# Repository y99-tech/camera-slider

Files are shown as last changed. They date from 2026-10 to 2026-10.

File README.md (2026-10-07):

# DIY Motorized Camera Slider (ESP32 · Wi-Fi + Bluetooth)

A 3D-printed, belt-driven camera slider on **four 10 mm steel rods with 608ZZ roller bearings**, sized for a
**Sony A7 IV + FE 24-70 mm F2.8 GM II** (≈ 1.4 kg, ≈ 1.8 kg with a ball head).
It's built from parts you can buy in Egyptian electronics/maker shops, and every printed part fits a
**Creality Ender-3 V3**.

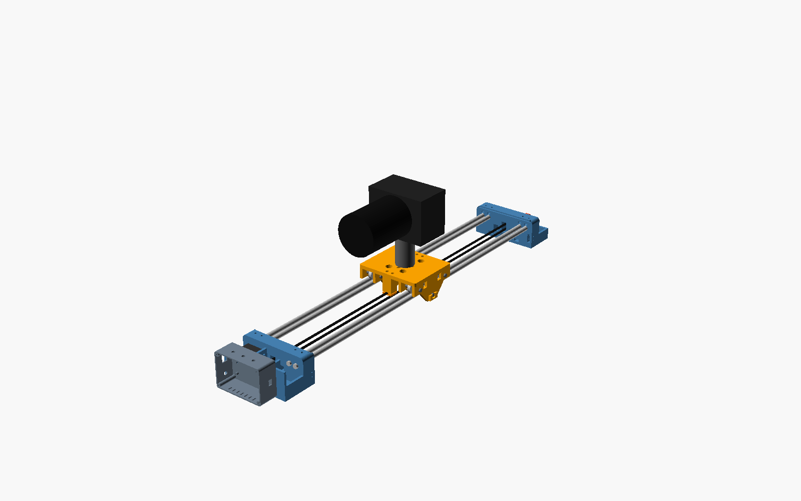
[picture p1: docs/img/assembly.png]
assembly


## Features

* **Mount it 3 ways:** on **2 tripods** (1/4"-20 and 3/8"-16 threads under each end), on **1 tripod**, or flat on a **table/floor** (optional wide feet).
* **Drive it 4 ways:**
  * **Motorized**: NEMA17 + silent TMC2209 driver, smooth eased moves for video
  * **By hand**: motor released, push the carriage
  * **Hand crank**: wheel on the idler end
  * **Fully free**: quick-release belt clamp
  * Also a rotary-knob "electronic hand wheel" on the control box
* **Control:**
  * **Wi-Fi web app** on any phone, no app to install. Uses its own hotspot or joins your Wi-Fi
  * **Bluetooth LE**: the same web page in Chrome, or any BLE-UART app
  * USB serial
  * Optional physical buttons
* **Moves:**
  * A→B with duration and ease, from 1 s to many hours
  * Bounce / loop
  * 6-keyframe sequencer
  * Shoot-move-shoot time-lapse with a camera shutter output
  * Stop-motion step
  * Homing with endstops, soft limits, and settings stored in flash

## Repository

| Folder | What's inside |
|---|---|
| [`cad/`](cad) | Parametric **OpenSCAD** source (`config.scad`, `parts.scad`, `assembly.scad`) and ready-to-print **STLs** in `cad/stl/` |
| [`firmware/`](firmware) | ESP32 firmware (PlatformIO / Arduino IDE) + the web UI (`firmware/ui/index.html`) |
| [`docs/SHOPPING_LIST.md`](docs/SHOPPING_LIST.md) | **Parts to buy**, with search keywords per shop group (+ [CSV](docs/SHOPPING_LIST.csv) to fill in prices) |
| [`docs/PRINTING.md`](docs/PRINTING.md) | Ender-3 V3 print settings, orientation, fit tuning |
| [`docs/WIRING.md`](docs/WIRING.md) | Pin map, power, motor current, endstops, shutter cable |
| [`docs/ASSEMBLY.md`](docs/ASSEMBLY.md) | Step-by-step build, mounting & hand-drive modes |
| [`docs/COMMANDS.md`](docs/COMMANDS.md) | Every command (Wi-Fi / Bluetooth / USB) and setting |

## Key specs

| | |
|---|---|
| Rails | 4 × 10 mm chrome rod, arranged as 2 twin-rod tracks 100 mm apart. 800 mm long (≈ 600 mm travel), up to 1000 mm |
| Bearings | 6 × 608ZZ rollers on M8 axles: 2 on top + 1 preloaded underneath per track. They roll in the groove between the two rods, with zero play and no sliding parts |
| Drive | NEMA17, GT2 6 mm belt, 20T pulleys → 80 steps/mm at 1/16 microstep |
| Speed | up to 120 mm/s (configurable), down to < 0.01 mm/s for long time-lapses |
| Controller | ESP32-WROOM-32 DevKit V1 + TMC2209 + LM2596 |
| Power | 12 V 2 A adapter or 3S 18650 pack |
| Camera mount | 3/8" centre hole + two 1/4" holes on the carriage, for a ball head or fluid head |

## Quick start

1. Buy the parts → [SHOPPING_LIST.md](docs/SHOPPING_LIST.md)
2. Print the STLs → [PRINTING.md](docs/PRINTING.md)
3. Wire it → [WIRING.md](docs/WIRING.md)
4. Assemble → [ASSEMBLY.md](docs/ASSEMBLY.md)
5. Flash the firmware → [firmware/README.md](firmware/README.md)
6. Join Wi-Fi **CamSlider-XXXX** (pw `slider123`), open **http://192.168.4.1**, press **Home**.

## Credits / inspiration

Feature ideas (A-B with ease, bounce, keyframe sequencer, time-lapse, stop motion) were inspired by the
excellent open-source [DigitalBird Camera Slider](https://github.com/digitalbird01/DigitalBird-Camera-Slider)
project ([Thingiverse](https://www.thingiverse.com/colinh3d/designs) ·
[YouTube](https://www.youtube.com/channel/UC7_bqm5Ea4Gn_P09HKYqyQA)). This repository is an independent
design. No DigitalBird files or code are copied here. If you want a pan/tilt head or a more complete
system, check out their designs and PCBs.

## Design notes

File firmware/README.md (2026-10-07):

# Firmware (ESP32)

ESP32 Arduino firmware built on [FastAccelStepper](https://github.com/gin66/FastAccelStepper) for smooth
step generation and [NimBLE-Arduino](https://github.com/h2zero/NimBLE-Arduino) for Bluetooth.

* `ui/index.html` is the control page. It's built into the firmware at compile time (`scripts/embed_ui.py`
  → `src/web_ui.h`). Edit the HTML, not the header.
* Everything goes through one text command parser (`src/commands.cpp`), whether it comes from Wi-Fi,
  Bluetooth, USB or the buttons.

## Flash with PlatformIO (recommended)

1. Install [VS Code](https://code.visualstudio.com) + the **PlatformIO** extension (or `pip install platformio`).
2. Open the `firmware` folder.
3. Plug in the ESP32 by USB (switch the slider's 12 V **off**). Then:
   ```
   pio run -t upload
   pio device monitor
   ```
   Some boards need the **BOOT** button held while "Connecting…" shows.
4. You should see:
   ```
   === DIY Camera Slider ===
   Wi-Fi AP "CamSlider-1A2B" password "slider123"  ->  http://192.168.4.1
   Bluetooth LE: advertising as "CamSlider"
   ```

USB driver: most DevKit V1 boards use **CP2102** or **CH340**. Install that driver on Windows if no COM port shows up.

## Flash with Arduino IDE

1. Boards Manager → install **esp32 by Espressif**, version **2.0.17**.
2. Library Manager → install **FastAccelStepper** (0.31.x) and **NimBLE-Arduino** (**1.4.x**, not 2.x).
3. Make a folder `CameraSlider`, copy all files from `src/` into it, add an empty `CameraSlider.ino`.
   Run `python scripts/embed_ui.py` first if you changed the HTML.
4. Board **ESP32 Dev Module**, Partition Scheme **Huge APP (3MB No OTA)**. Upload.

## Using it

### Wi-Fi (phone or laptop)
* Join **CamSlider-XXXX** (password `slider123`) → open **http://192.168.4.1**.
* Or set your home/studio Wi-Fi in *Settings* (name + password → Save → Reboot). Then open
  **http://slider.local** (or the IP printed on the serial monitor).

### Bluetooth
* **Android / desktop Chrome:** copy `ui/index.html` to the phone and open it in Chrome (or host it on
  GitHub Pages), tap **Bluetooth**, pick *CamSlider*. Same page, no Wi-Fi needed.
* **iPhone:** Safari has no Web Bluetooth. Use the free **Bluefruit Connect** or **nRF Connect** app →
  UART, and type the commands (e.g. `RUN 30 40 1`). Or use the Wi-Fi page.
* **Android terminal:** "Serial Bluetooth Terminal" app → Devices → Bluetooth LE → CamSlider.

### Commands
See [../docs/COMMANDS.md](../docs/COMMANDS.md).

## Tested

Compiled against Arduino-ESP32 2.0.17, FastAccelStepper 0.31.2 and NimBLE-Arduino 1.4.2
(sketch ≈ 1.1 MB, 35 % of the Huge APP partition). It hasn't run on real hardware yet, so check
direction and endstops with the camera off the first time.

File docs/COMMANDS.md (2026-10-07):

# Commands

The same text commands work over **USB serial** (115200 baud), **Bluetooth LE** (Nordic UART service,
device name `CamSlider`) and **Wi-Fi** (`http://<slider>/cmd?c=<command>`). Not case-sensitive.
Positions are in **mm from the motor end** (after homing).

| Command | What it does |
|---|---|
| `HELP` | list commands |
| `STATUS` | JSON: position, mode, A/B, homed, endstops … |
| `HOME` | find the MIN endstop (motor end), back off 3 mm, set 0 |
| `ZERO` | "here is 0" (use when endstops are disabled) |
| `STOP` / `ESTOP` | smooth stop / immediate stop, cancels any job |
| `GOTO <mm> [mm/s]` | go to a position at max (or given) speed |
| `JOG <mm>` | relative move (+ = toward idler end) |
| `MOVE <mm> <sec> [ease%]` | timed move to a position |
| `SETA [mm]`, `SETB [mm]` | store A / B (current position if no value) |
| `GOA`, `GOB` | go to A / B |
| `RUN [sec] [ease%] [legs]` | cinematic A↔B move. legs: `1` one way, `2` there and back, `0` bounce forever. Starts from the nearer end |
| `KEY ADD [mm] [sec]` | add keyframe (max 6). `sec` = time to reach this key from the previous one |
| `KEY LIST`, `KEY CLR` | list / delete keyframes |
| `SEQ [loops]` | play keyframes (ping-pong), `0` = forever |
| `TL <shots> <interval s> [settle ms] [shutter ms]` | shoot-move-shoot time-lapse from A to B |
| `SNAP [-]` | stop-motion: move one step (`smstep`) toward B (or back with `-`) and fire the shutter |
| `SHUTTER [ms]` | test the shutter output |
| `MOTOR ON` / `MOTOR OFF` | motor holding / hand mode |
| `SET <key> <value>` | change a setting (see below) |
| `SAVE` | store settings in flash |
| `CONFIG` | settings as JSON |
| `RESET` | factory defaults |
| `WIFI` | show the IP / hotspot name |
| `REBOOT` | restart |

### Settings (`SET`)

| Key | Default | Meaning |
|-----|---|---|
| `spm` | 80 | steps per mm (200 × 16 / (20 teeth × 2 mm)) |
| `vmax` | 120 | max speed mm/s |
| `accel` | 250 | acceleration mm/s² |
| `travel` | 600 | usable travel mm |
| `hspeed` | 25 | homing speed mm/s |
| `invert` | 0 | reverse motor direction |
| `endstops` | 1 | 0 = no switches fitted |
| `homeboot` | 0 | home automatically at power-on |
| `ease` | 30 | % of the move spent speeding up and slowing down. 0 = linear, 100 = all ramp |
| `secs` | 20 | default RUN duration |
| `smstep` | 2 | stop-motion step mm |
| `ssid` / `pass` | – | join your Wi-Fi instead of making a hotspot (`SET ssid -` clears it). Needs `SAVE` + `REBOOT` |
| `appass` | slider123 | hotspot password (8+ chars) |

### Local buttons / knob (optional hardware)

| Control | Short press | Long press (0.8 s) |
|---|---|---|
| Button 1 | RUN (or stop if moving) | Set A here |
| Button 2 | STOP | Set B here |
| Knob turn | jog 5 mm per click (0.5 mm fine) | – |
| Knob press | toggle fine / coarse | motor on / off (hand mode) |

### Status LED

solid = ready · slow blink = not homed · fast blink = moving · double blink = hand mode

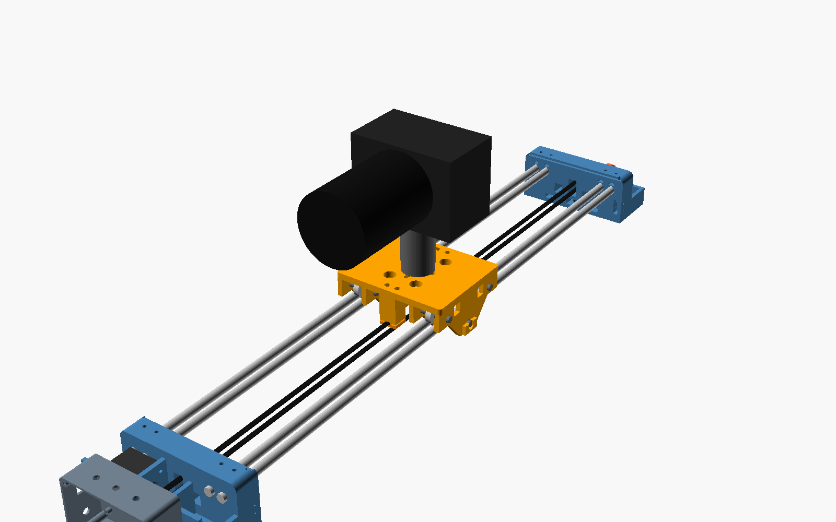
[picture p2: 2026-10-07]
docs/img/view_overview.png

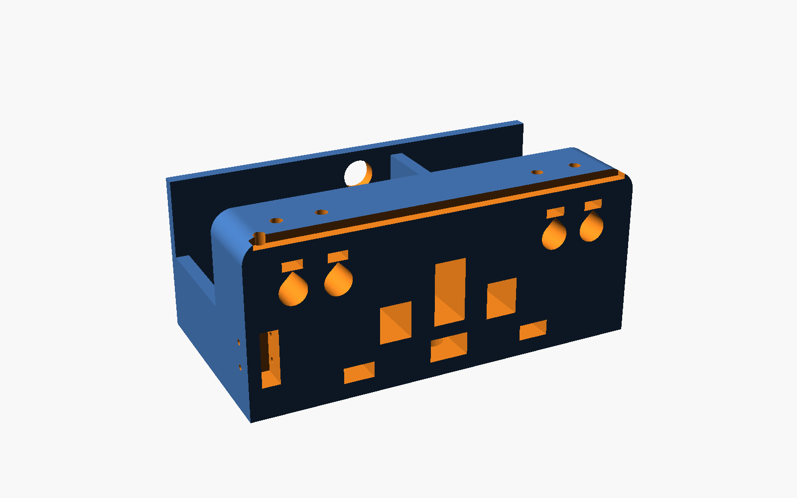
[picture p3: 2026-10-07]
docs/img/me_inner.png

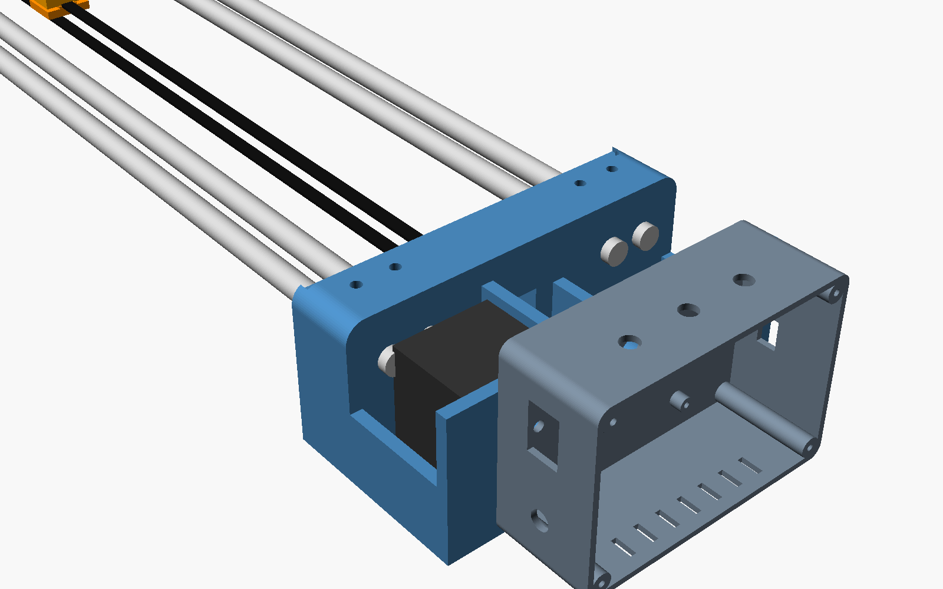
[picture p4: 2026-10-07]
docs/img/view_motor_end.png

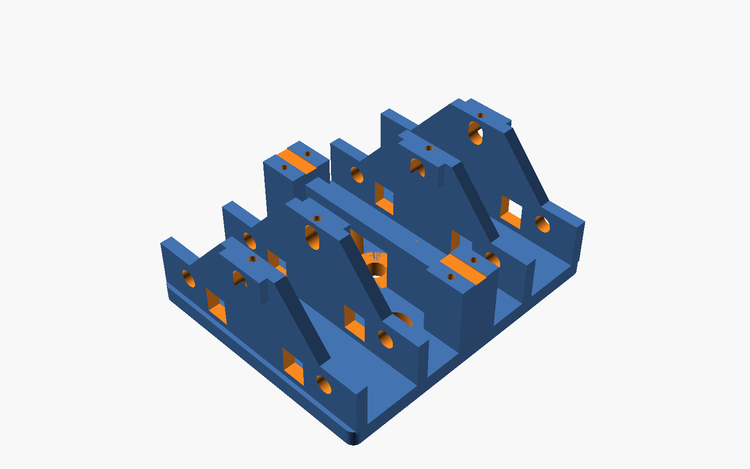
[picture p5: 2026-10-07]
docs/img/carriage.png

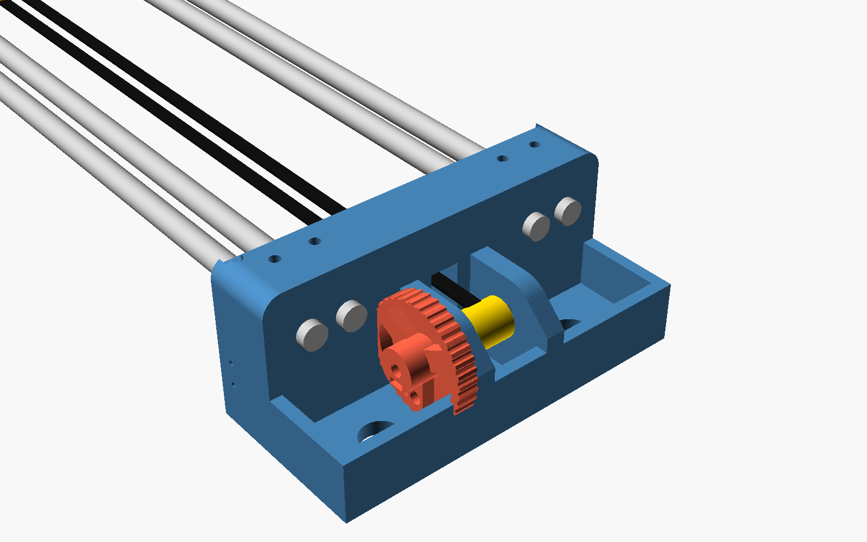
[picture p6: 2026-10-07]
docs/img/view_idler_end.png

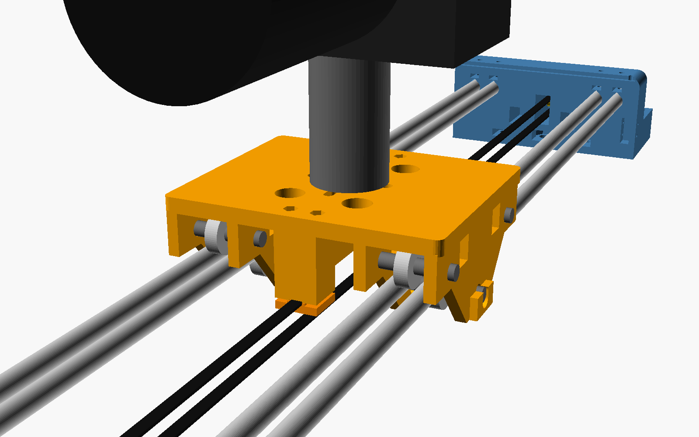
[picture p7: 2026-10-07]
docs/img/view_carriage.png

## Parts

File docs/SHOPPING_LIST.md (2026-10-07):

# Shopping / Search List

This is the list to search on the Egyptian shops you gave. I couldn't reach the
shops myself, so the **"Try first"** column is only a guess at which kind of
shop is most likely to stock each item. Write the price and link you find in the
last two columns (or in `SHOPPING_LIST.csv`).

Sized for: **Sony A7 IV (≈660 g) + FE 24-70 GM II (≈695 g) + ball head (≈400 g) ≈ 1.8 kg**,
on **4 × 10 mm rods** (2 twin-rod tracks) with **608ZZ roller bearings**, 800 mm rail by default (up to 1000 mm).

Shop groups used below:

* **ELEC** – ram-e-shop.com, makerselectronics.com, store.fut-electronics.com, free-electronic.com,
  uge-one.com, electrolik-eg.com, circuits-elec.com, microohm-eg.com, ampere-eg.com, sigmastore.net,
  3duino.com, mokwn.com, shop.electech.com.eg, shop.hak.com.eg, lampatronics.com, emtech-eg.com,
  metanoia-tech.com, norisolutions.com, ekostra.com, justpiece.com
* **MECH** – cncegy.com, mechatronics-store.com, alexautomation-eg.com, eisac-automation.com,
  ram-e-shop.com, makerselectronics.com, store.fut-electronics.com
* **3DP** – 3dsmart-shop.com, in3d-shop.com, lancer3d.com, hawk3dvision.com, 3duino.com

---

## A. Motion parts (most important – buy these first)

| # | Item | Spec / what to check | Qty | Search keywords | Try first | Price | Link |
|---|---|---|-----|---|---|---|---|
| A1 | Smooth rod 10 mm | **you already have 4.** Chrome hardened, all the same length (800–1000 mm), straight. Roll each on a glass table: a bent one wobbles | 4 | `10mm linear rod`, `10mm smooth rod`, `chrome shaft 10mm`, `optical axis 10mm` | MECH | | |
| A2 | **Roller bearing 608ZZ** (or 608-2RS) | 8×22×7 mm skateboard bearing. Get a **good brand** (SKF / NSK / NTN / FAG or ABEC-7 skate bearings): the smoothness of the slide comes from these | 8 (6 + 2 spare) | `608ZZ`, `608 bearing`, `bearing 8x22x7`, `skate bearing ABEC 7` | MECH, 3DP | | |
| A3 | Stepper motor NEMA17 | 42×42 mm, 40–48 mm long, 1.5–2.0 A, 5 mm shaft (e.g. 17HS4401, 17HS8401) | 1 | `NEMA17`, `17HS4401`, `stepper motor 42`, `42 stepper` | ELEC, MECH | | |
| A4 | Stepper driver TMC2209 | module (BigTreeTech / FYSETC style). Silent = needed for video | 1 | `TMC2209`, `TMC2209 driver`, `silent stepper driver` | ELEC, 3DP | | |
| A4b | *(fallback)* A4988 or DRV8825 | only if no TMC2209; louder | 1 | `A4988`, `DRV8825` | ELEC | | |
| A5 | GT2 pulley 20 teeth | **5 mm bore**, for **6 mm** belt | 2 | `GT2 pulley 20T 5mm`, `GT2 20 teeth pulley` | ELEC, 3DP, MECH | | |
| A6 | GT2 timing belt | **6 mm** wide, open belt. 2 m for 800 mm rail (2.5 m for 1000 mm) | 2 m | `GT2 belt 6mm`, `GT2 timing belt`, `2GT belt` | ELEC, 3DP, MECH | | |
| A7 | Ball bearing 625ZZ | 5×16×5 mm (hand-crank shaft) | 2 | `625ZZ`, `625 bearing`, `bearing 5x16x5` | MECH, 3DP | | |
| A8 | Shaft 5 mm | smooth rod, cut to ~70 mm (or use an M5×70 bolt) | 1 | `5mm linear rod`, `5mm shaft`, `5mm smooth rod` | MECH | | |
| A9 | Micro limit switch | **KW11-3Z** with a short straight lever (20×10×6.4 mm body). It sits in a pocket in each end block | 2 | `KW11 limit switch`, `micro switch lever`, `endstop switch` | ELEC, 3DP | | |

## B. Electronics

| # | Item | Spec / what to check | Qty | Search keywords | Try first | Price | Link |
|---|---|---|-----|---|---|---|---|
| B1 | ESP32 dev board | **ESP32-WROOM-32 DevKit V1 (30 or 38 pin)** – has Wi-Fi **and** Bluetooth. Not ESP32-S2 (no BT), not ESP8266 | 1 | `ESP32 devkit`, `ESP32 WROOM 32`, `NodeMCU ESP32` | ELEC | | |
| B2 | Buck converter 12 V → 5 V | LM2596 module (adjustable) or MP1584 / Mini-360 | 1 | `LM2596`, `step down converter`, `buck converter` | ELEC | | |
| B3 | Power adapter 12 V | 12 V **2 A** (or 3 A), 5.5×2.1 mm plug | 1 | `12V 2A adapter`, `12V power supply 5.5` | ELEC | | |
| B4 | DC jack, panel mount | 5.5×2.1 mm female, 8 mm hole | 1 | `DC jack panel 5.5 2.1`, `DC005` (PCB) or `DC-022` (panel) | ELEC | | |
| B5 | Rocker switch | KCD1 small (21×15 mm, 19×13 cut-out) | 1 | `KCD1 rocker switch`, `rocker switch 2 pin` | ELEC | | |
| B6 | Electrolytic capacitor | 100 µF 35 V (across driver motor supply) | 1 | `100uf 35v capacitor` | ELEC | | |
| B7 | Perfboard | 7×5 cm (double-sided is nicer) | 1 | `perfboard 7x5`, `PCB prototype board 5x7` | ELEC | | |
| B8 | Female pin headers | 1×40 pin, 2.54 mm (to socket ESP32 + driver) | 2 | `female header 40 pin` | ELEC | | |
| B9 | Connectors | JST-XH 2.54 kit **or** Dupont kit; screw terminal 2-pin ×2 | 1 kit | `JST XH connector kit`, `dupont connector kit`, `terminal block 2 pin` | ELEC | | |
| B10 | Motor cable | 4-core, ~1 m (or the cable that comes with the motor) | 1 | `4 core cable`, `stepper motor cable` | ELEC | | |
| B11 | Hook-up wire | 22 AWG silicone or solid, few colours | 1 set | `22AWG wire`, `jumper wire` | ELEC | | |

### B-optional (nice to have)

| # | Item | Spec | Qty | Search keywords | Try first | Price | Link |
|---|---|---|-----|---|---|---|---|
| B12 | Rotary encoder | KY-040 module (or EC11 + knob). "Electronic hand wheel" + menu | 1 | `KY-040`, `rotary encoder module` | ELEC | | |
| B13 | Push buttons | 12 mm panel / tactile with cap | 2 | `push button 12mm`, `tactile switch 12x12` | ELEC | | |
| B14 | LED 5 mm + 330 Ω resistor | status | 1 | `LED 5mm`, `resistor 330 ohm` | ELEC | | |
| B15 | Optocoupler PC817 + 1 kΩ resistor | camera shutter output (time-lapse) | 1 | `PC817` | ELEC | | |
| B16 | 3S battery: 3× 18650 cells + 3S BMS + 3S holder | cordless use (≈11.1 V) | 1 set | `18650 battery`, `3S BMS 20A`, `18650 holder 3` | ELEC | | |
| B16b | *(alt.)* 12 V power bank / 3S Li-ion pack with DC out | cordless use | 1 | `12V lithium battery pack`, `12V power bank DC` | ELEC | | |
| B17 | Heat-shrink tube | assorted | 1 | `heat shrink` | ELEC | | |

### B-soldering (needed to build the perfboard)

| # | Item | Spec | Qty | Search keywords | Try first | Price | Link |
|---|---|---|-----|---|---|---|---|
| B18 | **Soldering flux** | no-clean **paste** (e.g. RMA-223 / AMTECH style) or a **flux pen**. Avoid acid flux (plumbing type) because it corrodes electronics | 1 | `soldering flux`, `flux paste`, `RMA-223`, `flux pen`, `no clean flux` | ELEC | | |
| B19 | Solder wire | 0.6–0.8 mm, 63/37 or 60/40 with a rosin core | 1 roll | `solder wire 0.8mm`, `tin solder 63/37` | ELEC | | |
| B20 | Desoldering wick | 2–2.5 mm | 1 | `desoldering wick`, `solder wick` | ELEC | | |
| B21 | Isopropyl alcohol (IPA) 99 % | cleans flux off the board | 1 | `isopropyl alcohol 99`, `IPA` | ELEC | | |

## C. Screws, nuts, small parts

| # | Item | Qty | Used for | Search keywords | Try first | Price | Link |
|---|---|-----|---|---|---|---|---|
| C1 | M3×10 socket screw | 4 | NEMA17 to motor plate | `M3 screw 10mm`, `M3 allen bolt` | ELEC, 3DP, MECH | | |
| C2 | M3×16 socket screw | 4 | belt clamps | `M3x16` | ″ | | |
| C3 | **M8×50 bolt** (hex or socket head) | 4 | top roller axles | `M8x50 bolt`, `M8 screw 50mm` | ″ | | |
| C3b | **M8×60 bolt** | 2 | bottom (preload) roller axles | `M8x60 bolt` | ″ | | |
| C3c | M8 nyloc nut + 2 M8 washers each | 6 + 12 | roller axles | `M8 nylock nut`, `M8 washer` | ″ | | |
| C3d | M4×12 screw | 4 | push the bottom rollers up (preload) | `M4x12` | ″ | | |
| C4 | M3×8 screw | 4 | box lid | `M3x8` | ″ | | |
| C5 | M3 hex nut | 10 | belt clamps, clips, wheel | `M3 nut` | ″ | | |
| C6 | M3 grub (set) screw ×4–6 mm | 1 | hand wheel on shaft | `M3 grub screw`, `M3 set screw` | ″ | | |
| C7 | M4×16 screw | 8 | rod set-screws in end blocks (2 per block per track) | `M4x16` | ″ | | |
| C8 | M4×12 screw | 2 | electronics box to end block | `M4x12` | ″ | | |
| C9 | M4 hex nut | 10 | | `M4 nut` | ″ | | |
| C10 | M2×10 screw + nut | 4 | micro switches | `M2 screw` | ″ | | |
| C11 | M5×30 bolt + nyloc nut | 1 | crank handle on hand wheel | `M5x30`, `M5 nylock nut` | ″ | | |
| C12 | M5 washers | 4 | shims on idler shaft | `M5 washer` | ″ | | |
| C13 | **1/4"-20 hex nut** | 4 | tripod threads in end blocks | `1/4 inch nut`, `1/4-20 nut`, `UNC 1/4 nut`, `camera screw nut` | MECH, hardware store | | |
| C14 | **3/8"-16 hex nut** | 2 | tripod threads in end blocks | `3/8 inch nut`, `3/8-16 nut`, `UNC 3/8 nut` | MECH, hardware store | | |
| C15 | 3/8"-16 × 5/8" screw (or 1/4"-20 × 5/8") | 1 | ball head to carriage | `3/8 camera screw`, `1/4 camera screw` | photo store / AliExpress | | |
| C16 | Zip ties 3 mm | 10 | bearings, cables | `cable tie` | ELEC | | |
| C17 | Rubber feet / pads 20 mm | 4–8 | table feet | `rubber feet`, `silicone bumper` | ELEC | | |

> 1/4"-20 and 3/8"-16 are **inch** (UNC) threads – the same as every tripod and camera.
> If the electronics shops don't stock them, try a hardware shop (search "صامولة بوصة 1/4") or a
> photography shop (look for "1/4 to 3/8 screw adapter" kits – they often include nuts).

## D. Camera side (photography store, not in the list above)

| # | Item | Spec | Qty |
|---|---|---|-----|
| D1 | Ball head or small fluid head | ≥ 5 kg rated, **3/8" thread underneath**, Arca-Swiss clamp | 1 |
| D2 | Arca-Swiss plate for A7 IV | or an L-bracket | 1 |
| D3 | Tripods | any with 1/4" or 3/8" screw. Use 1 at each end of the rail | 1–2 |

## E. 3-D printing

| # | Item | Spec | Qty | Search keywords | Try first | Price | Link |
|---|---|---|-----|---|---|---|---|
| E1 | **PETG filament 1.75 mm** | 1 kg is enough for everything (≈ 600 g used). PETG is stiffer in the sun / car than PLA | 1 | `PETG 1.75`, `PETG filament` | 3DP | | |
| E2 | *(alt.)* PLA+ 1.75 mm | fine for indoor use | 1 | `PLA plus 1.75` | 3DP | | |

---

### Arabic search keywords (if a shop's search is in Arabic)

| English | Arabic |
|---|---|
| smooth rod 10 mm | عمود خطي 10 مم |
| ball bearing 608 | رولمان بلي 608 |
| linear bearing | رولمان بلي خطي |
| stepper motor | موتور ستيبر |
| timing belt | سير جي تي 2 |
| pulley | بكرة |
| limit switch | ليمت سويتش |
| power adapter | محول باور 12 فولت |
| screw / nut | مسمار / صامولة |
| filament | خيط طباعة ثلاثية الأبعاد |
| soldering flux | فلكس لحام / معجون لحام |
| solder wire | سلك قصدير لحام |

### Rough budget

Can't confirm prices from here – fill in the table. The most expensive items will be the
608ZZ bearings (if you buy a good brand), NEMA17, TMC2209 and ESP32. You already have the rods.

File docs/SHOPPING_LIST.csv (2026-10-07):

Section | # | Item | Spec / used for | Qty | Search keywords | Try first | Price EGP | Link
A. Motion parts (most important – buy these first) | A1 | Smooth rod 10 mm | you already have 4; chrome hardened, same length 800-1000 mm, straight | 4 | 10mm linear rod, 10mm smooth rod, chrome shaft 10mm, optical axis 10mm | MECH
A. Motion parts (most important – buy these first) | A2 | Roller bearing 608ZZ (or 608-2RS) | 8x22x7 skate bearing, good brand (SKF/NSK/NTN/FAG or ABEC-7) | 8 (6 + 2 spare) | 608ZZ, 608 bearing, bearing 8x22x7, skate bearing ABEC 7 | MECH, 3DP
A. Motion parts (most important – buy these first) | A3 | Stepper motor NEMA17 | 42×42 mm, 40–48 mm long, 1.5–2.0 A, 5 mm shaft (e.g. 17HS4401, 17HS8401) | 1 | NEMA17, 17HS4401, stepper motor 42, 42 stepper | ELEC, MECH
A. Motion parts (most important – buy these first) | A4 | Stepper driver TMC2209 | module (BigTreeTech / FYSETC style). Silent = needed for video | 1 | TMC2209, TMC2209 driver, silent stepper driver | ELEC, 3DP
A. Motion parts (most important – buy these first) | A4b | *(fallback)* A4988 or DRV8825 | only if no TMC2209; louder | 1 | A4988, DRV8825 | ELEC
A. Motion parts (most important – buy these first) | A5 | GT2 pulley 20 teeth | 5 mm bore, for 6 mm belt | 2 | GT2 pulley 20T 5mm, GT2 20 teeth pulley | ELEC, 3DP, MECH
A. Motion parts (most important – buy these first) | A6 | GT2 timing belt | 6 mm wide, open belt. 2 m for 800 mm rail (2.5 m for 1000 mm) | 2 m | GT2 belt 6mm, GT2 timing belt, 2GT belt | ELEC, 3DP, MECH
A. Motion parts (most important – buy these first) | A7 | Ball bearing 625ZZ | 5×16×5 mm (hand-crank shaft) | 2 | 625ZZ, 625 bearing, bearing 5x16x5 | MECH, 3DP
A. Motion parts (most important – buy these first) | A8 | Shaft 5 mm | smooth rod, cut to ~70 mm (or use an M5×70 bolt) | 1 | 5mm linear rod, 5mm shaft, 5mm smooth rod | MECH
A. Motion parts (most important – buy these first) | A9 | Micro limit switch | KW11-3Z with short straight lever (20x10x6.4 body); fits a pocket in each end block | 2 | KW11 limit switch, micro switch lever, endstop switch | ELEC, 3DP
B. Electronics | B1 | ESP32 dev board | ESP32-WROOM-32 DevKit V1 (30 or 38 pin) – has Wi-Fi and Bluetooth. Not ESP32-S2 (no BT), not ESP8266 | 1 | ESP32 devkit, ESP32 WROOM 32, NodeMCU ESP32 | ELEC
B. Electronics | B2 | Buck converter 12 V → 5 V | LM2596 module (adjustable) or MP1584 / Mini-360 | 1 | LM2596, step down converter, buck converter | ELEC
B. Electronics | B3 | Power adapter 12 V | 12 V 2 A (or 3 A), 5.5×2.1 mm plug | 1 | 12V 2A adapter, 12V power supply 5.5 | ELEC
B. Electronics | B4 | DC jack, panel mount | 5.5×2.1 mm female, 8 mm hole | 1 | DC jack panel 5.5 2.1, DC005 (PCB) or DC-022 (panel) | ELEC
B. Electronics | B5 | Rocker switch | KCD1 small (21×15 mm, 19×13 cut-out) | 1 | KCD1 rocker switch, rocker switch 2 pin | ELEC
B. Electronics | B6 | Electrolytic capacitor | 100 µF 35 V (across driver motor supply) | 1 | 100uf 35v capacitor | ELEC
B. Electronics | B7 | Perfboard | 7×5 cm (double-sided is nicer) | 1 | perfboard 7x5, PCB prototype board 5x7 | ELEC
B. Electronics | B8 | Female pin headers | 1×40 pin, 2.54 mm (to socket ESP32 + driver) | 2 | female header 40 pin | ELEC
B. Electronics | B9 | Connectors | JST-XH 2.54 kit or Dupont kit; screw terminal 2-pin ×2 | 1 kit | JST XH connector kit, dupont connector kit, terminal block 2 pin | ELEC
B. Electronics | B10 | Motor cable | 4-core, ~1 m (or the cable that comes with the motor) | 1 | 4 core cable, stepper motor cable | ELEC
B. Electronics | B11 | Hook-up wire | 22 AWG silicone or solid, few colours | 1 set | 22AWG wire, jumper wire | ELEC
B-optional (nice to have) | B12 | Rotary encoder | KY-040 module (or EC11 + knob). "Electronic hand wheel" + menu | 1 | KY-040, rotary encoder module | ELEC
B-optional (nice to have) | B13 | Push buttons | 12 mm panel / tactile with cap | 2 | push button 12mm, tactile switch 12x12 | ELEC
B-optional (nice to have) | B14 | LED 5 mm + 330 Ω resistor | status | 1 | LED 5mm, resistor 330 ohm | ELEC
B-optional (nice to have) | B15 | Optocoupler PC817 + 1 kΩ resistor | camera shutter output (time-lapse) | 1 | PC817 | ELEC
B-optional (nice to have) | B16 | 3S battery: 3× 18650 cells + 3S BMS + 3S holder | cordless use (≈11.1 V) | 1 set | 18650 battery, 3S BMS 20A, 18650 holder 3 | ELEC
B-optional (nice to have) | B16b | *(alt.)* 12 V power bank / 3S Li-ion pack with DC out | cordless use | 1 | 12V lithium battery pack, 12V power bank DC | ELEC
B-optional (nice to have) | B17 | Heat-shrink tube | assorted | 1 | heat shrink | ELEC
B-soldering (needed to build the perfboard) | B18 | Soldering flux | no-clean paste (RMA-223 style) or flux pen; NOT acid/plumbing flux | 1 | soldering flux, flux paste, RMA-223, flux pen, no clean flux | ELEC
B-soldering (needed to build the perfboard) | B19 | Solder wire | 0.6-0.8 mm, 63/37 or 60/40 rosin core | 1 roll | solder wire 0.8mm, tin solder 63/37 | ELEC
B-soldering (needed to build the perfboard) | B20 | Desoldering wick | 2-2.5 mm | 1 | desoldering wick, solder wick | ELEC
B-soldering (needed to build the perfboard) | B21 | Isopropyl alcohol 99% | cleans flux off the board | 1 | isopropyl alcohol 99, IPA | ELEC
C. Screws, nuts, small parts | C1 | M3×10 socket screw | NEMA17 to motor plate | 4 | M3 screw 10mm, M3 allen bolt | ELEC, 3DP, MECH
C. Screws, nuts, small parts | C2 | M3×16 socket screw | belt clamps | 4 | M3x16 | ″
C. Screws, nuts, small parts | C3 | M8x50 bolt | top roller axles | 4 | M8x50 bolt, M8 screw 50mm | ELEC, 3DP, MECH
C. Screws, nuts, small parts | C3b | M8x60 bolt | bottom (preload) roller axles | 2 | M8x60 bolt | ELEC, 3DP, MECH
C. Screws, nuts, small parts | C3c | M8 nyloc nut + M8 washers | roller axles | 6 + 12 | M8 nylock nut, M8 washer | ELEC, 3DP, MECH
C. Screws, nuts, small parts | C3d | M4x12 screw | preload screws under bottom rollers | 4 | M4x12 | ELEC, 3DP, MECH
C. Screws, nuts, small parts | C4 | M3×8 screw | box lid | 4 | M3x8 | ″
C. Screws, nuts, small parts | C5 | M3 hex nut | belt clamps, clips, wheel | 10 | M3 nut | ″
C. Screws, nuts, small parts | C6 | M3 grub (set) screw ×4–6 mm | hand wheel on shaft | 1 | M3 grub screw, M3 set screw | ″
C. Screws, nuts, small parts | C7 | M4×16 screw | rod set-screws in end blocks | 8 | M4x16 | ″
C. Screws, nuts, small parts | C8 | M4×12 screw | electronics box to end block | 2 | M4x12 | ″
C. Screws, nuts, small parts | C9 | M4 hex nut |  | 10 | M4 nut | ″
C. Screws, nuts, small parts | C10 | M2×10 screw + nut | micro switches | 4 | M2 screw | ″
C. Screws, nuts, small parts | C11 | M5×30 bolt + nyloc nut | crank handle on hand wheel | 1 | M5x30, M5 nylock nut | ″
C. Screws, nuts, small parts | C12 | M5 washers | shims on idler shaft | 4 | M5 washer | ″
C. Screws, nuts, small parts | C13 | **1/4"-20 hex nut** | tripod threads in end blocks | 4 | 1/4 inch nut, 1/4-20 nut, UNC 1/4 nut, camera screw nut | MECH, hardware store
C. Screws, nuts, small parts | C14 | **3/8"-16 hex nut** | tripod threads in end blocks | 2 | 3/8 inch nut, 3/8-16 nut, UNC 3/8 nut | MECH, hardware store
C. Screws, nuts, small parts | C15 | 3/8"-16 × 5/8" screw (or 1/4"-20 × 5/8") | ball head to carriage | 1 | 3/8 camera screw, 1/4 camera screw | photo store / AliExpress
C. Screws, nuts, small parts | C16 | Zip ties 3 mm | bearings, cables | 10 | cable tie | ELEC
C. Screws, nuts, small parts | C17 | Rubber feet / pads 20 mm | table feet | 4–8 | rubber feet, silicone bumper | ELEC
E. 3-D printing | E1 | **PETG filament 1.75 mm** | 1 kg is enough for everything (≈ 600 g used). PETG is stiffer in the sun / car than PLA | 1 | PETG 1.75, PETG filament | 3DP
E. 3-D printing | E2 | *(alt.)* PLA+ 1.75 mm | fine for indoor use | 1 | PLA plus 1.75 | 3DP

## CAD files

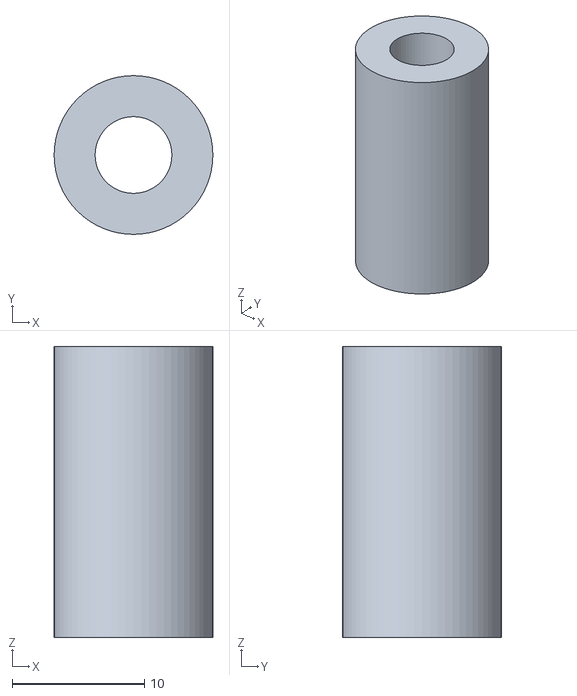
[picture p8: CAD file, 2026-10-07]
cad/stl/crank_spinner.stl
12.0 x 12.0 x 22.0

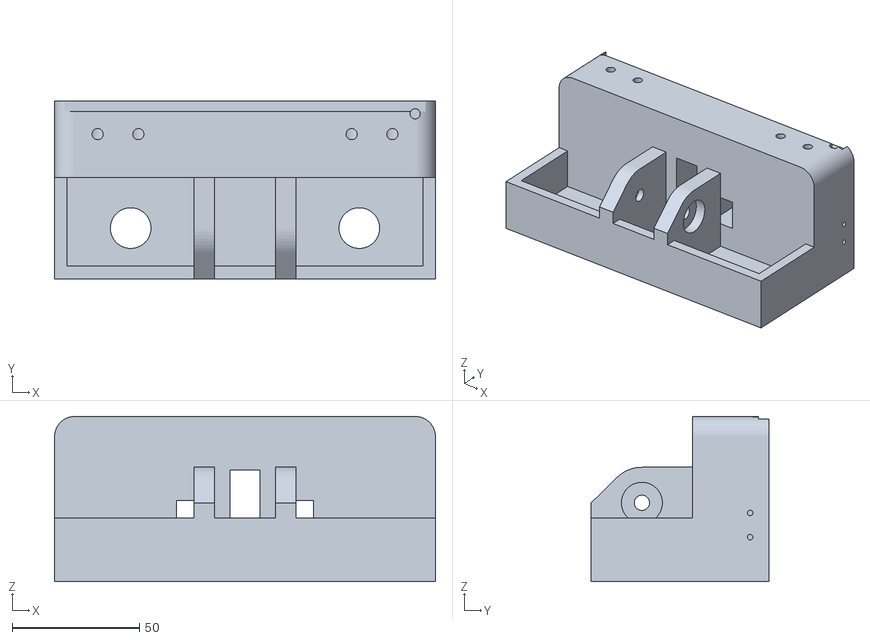
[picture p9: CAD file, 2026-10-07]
cad/stl/idler_end.stl
150.0 x 70.0 x 65.0

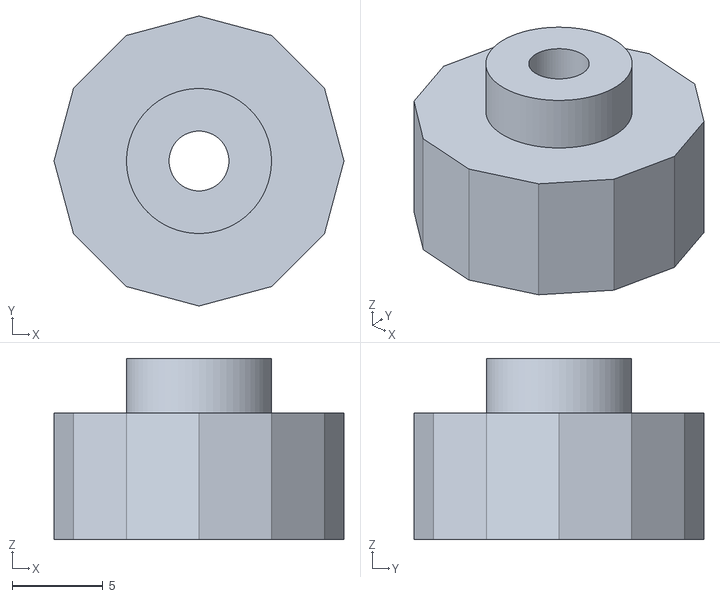
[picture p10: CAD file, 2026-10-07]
cad/stl/thumb_knob.stl
16.0 x 16.0 x 10.0

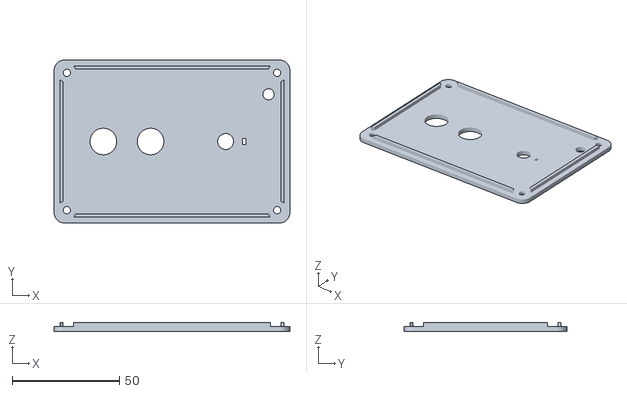
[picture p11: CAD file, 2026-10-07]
cad/stl/elec_lid.stl
110.0 x 76.0 x 4.40

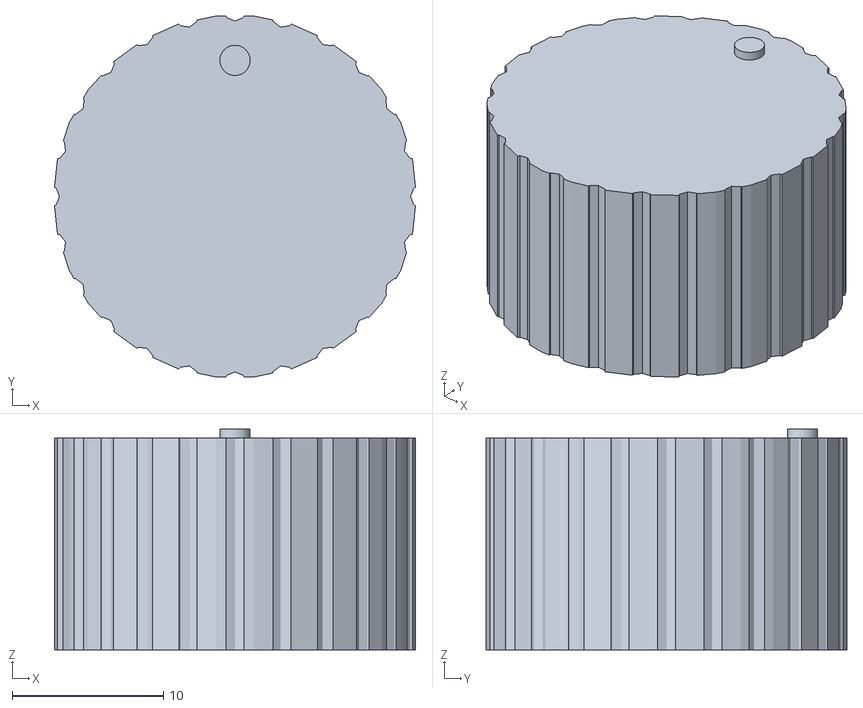
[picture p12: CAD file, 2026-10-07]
cad/stl/encoder_knob.stl
23.9 x 23.9 x 14.6

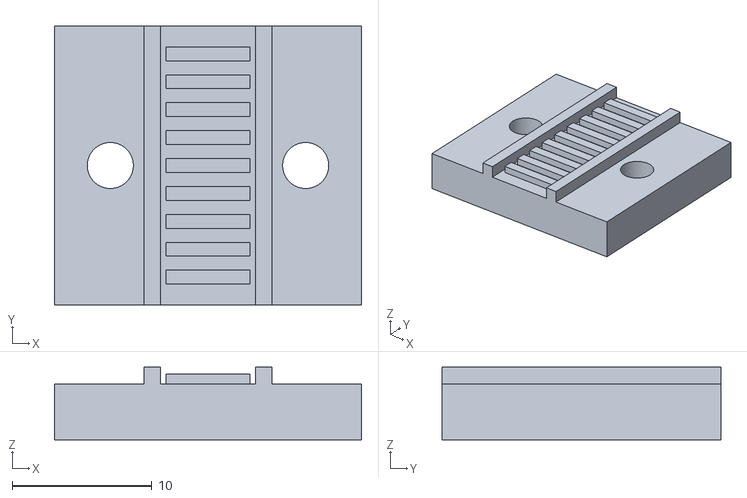
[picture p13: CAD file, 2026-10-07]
cad/stl/belt_clamp_plate.stl
22.0 x 20.0 x 5.20

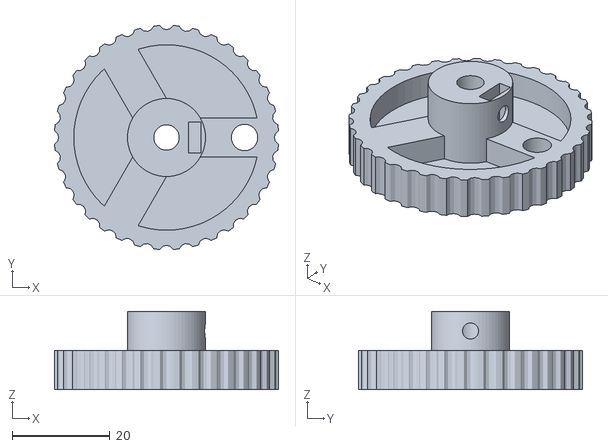
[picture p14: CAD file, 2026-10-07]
cad/stl/hand_wheel.stl
45.9 x 45.9 x 16.0

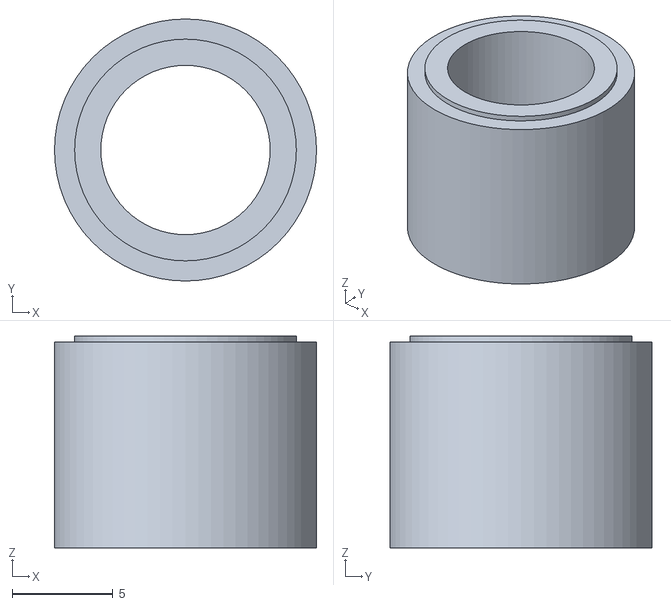
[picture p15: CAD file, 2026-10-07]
cad/stl/roller_spacer.stl
13.0 x 13.0 x 10.5

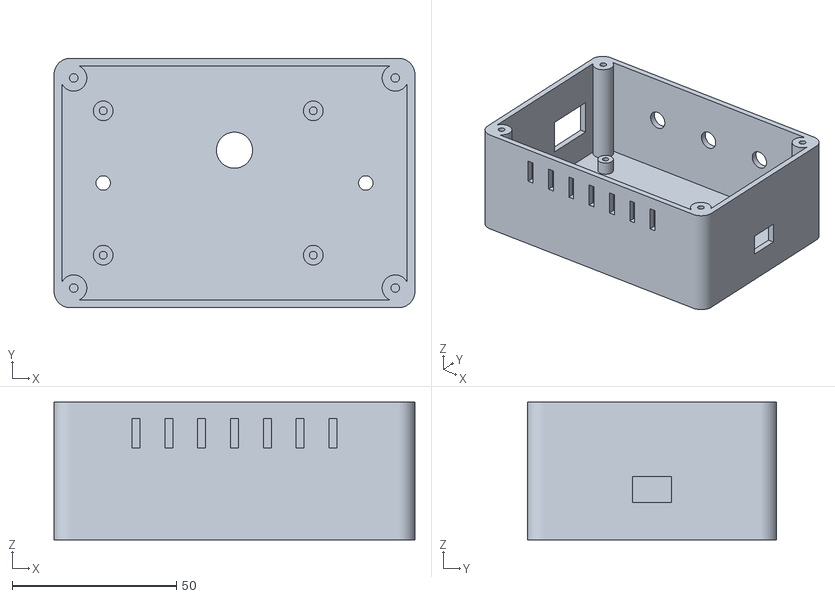
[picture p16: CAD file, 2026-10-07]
cad/stl/elec_box.stl
110.0 x 76.0 x 42.0

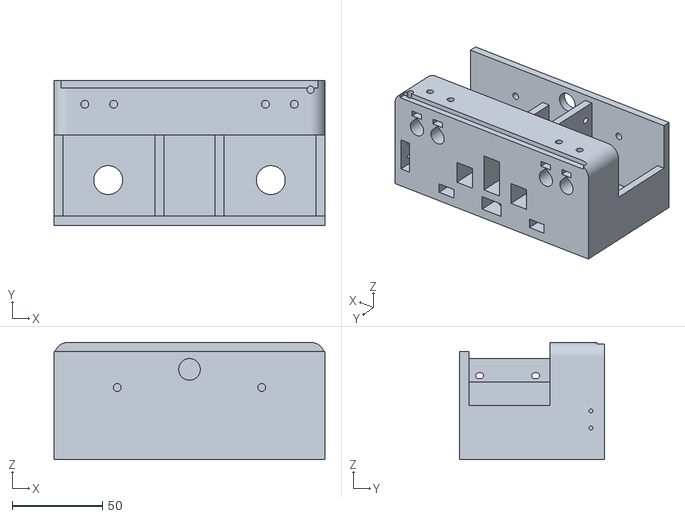
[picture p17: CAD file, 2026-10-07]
cad/stl/motor_end.stl
150.0 x 80.0 x 65.0

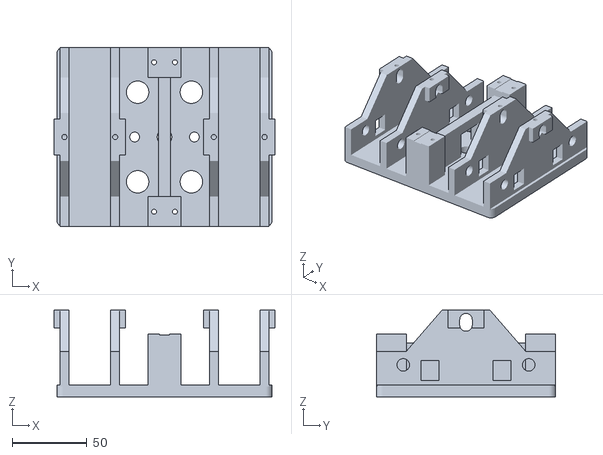
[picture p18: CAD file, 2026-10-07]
cad/stl/carriage.stl
148.0 x 120.0 x 58.2

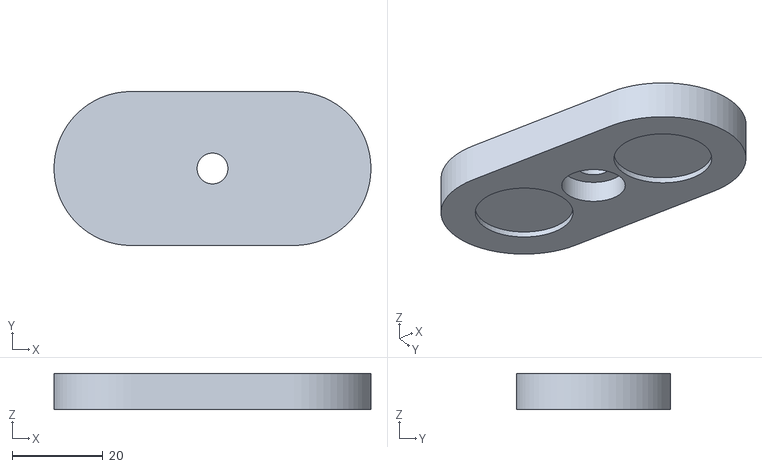
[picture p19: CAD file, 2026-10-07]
cad/stl/table_foot.stl
70.0 x 34.0 x 8.00

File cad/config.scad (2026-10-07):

// ============================================================
//  Camera Slider - shared parameters
//  Units: mm.  Axes: X = across the rail, Y = along the rail, Z = up.
//  Edit values here, then re-run ./cad/export_stl.sh
// ============================================================

$fn = 64;

// ---------- Rails: 4 rods = 2 "twin-rod" tracks ----------
// Each track is two parallel rods; 608ZZ rollers ride in the groove
// between them (2 on top + 1 preloaded underneath per track).
rod_d        = 10;      // smooth rod diameter (4 rods)
rod_hole     = 10.25;   // printed hole for the rod (tune to your printer)
track_sp     = 100;     // centre-to-centre distance of the two tracks
pair_sp      = 16;      // centre-to-centre distance of the 2 rods in one track
rod_z        = 45;      // rod centre height above the ground plane
rail_len     = 800;     // rod length (only used for the assembly preview)
rod_insert   = 26;      // how deep the rods go into each end block

// rod X positions (all four)
rod_xs = [-track_sp/2 - pair_sp/2, -track_sp/2 + pair_sp/2,
           track_sp/2 - pair_sp/2,  track_sp/2 + pair_sp/2];

// ---------- Rollers (608ZZ skate bearings) ----------
roller_od    = 22;
roller_w     = 7;
axle_d       = 8;       // M8 bolt
// height of a roller centre above (top) / below (bottom) the rod centres
roller_dz    = sqrt(pow(roller_od/2 + rod_d/2, 2) - pow(pair_sp/2, 2));
roller_y     = 42;      // top rollers at +-roller_y from carriage centre

// ---------- Motor / belt ----------
nema_w       = 42.3;    // NEMA17 body
nema_hole_sp = 31;
nema_boss    = 23;      // clearance for the 22 mm centring boss
pulley_z     = rod_z - 14;   // height of the pulley axis (both ends)
pulley_pd    = 12.73;        // GT2 20T pitch diameter
belt_w       = 6;
belt_top_z   = pulley_z + pulley_pd/2;   // centre of the upper belt run

// ---------- End blocks ----------
end_w        = 150;     // width across X
end_d        = 30;      // depth of the rod-clamp section (Y)
end_h        = rod_z + 20;
floor_t      = 6;
motor_bay_d  = 50;      // outboard section on the motor end
idler_bay_d  = 40;      // outboard section on the idler end
pulley_y_motor = -24;   // pulley axis Y position (outboard, negative Y)
pulley_y_idler = -20;

// ---------- Carriage ----------
car_w        = 144;
car_l        = 120;
car_t        = 8;
car_z0       = rod_z + roller_dz + roller_od/2 + 2.5;   // bottom of the top plate
cheek_t      = 6;
cheek_in     = track_sp/2 - pair_sp/2 - rod_d/2 - 1;    // inner cheek outer face (|x|)
cheek_out    = track_sp/2 + pair_sp/2 + rod_d/2 + 1;    // outer cheek inner face (|x|)
cheek_bot    = rod_z - roller_dz - 9;                   // bottom of the cheeks

// ---------- Hardware ----------
m3_hole  = 3.3;   m3_nut  = 6.4;  m3_nut_t = 2.6;
m4_hole  = 4.4;   m4_nut  = 7.3;  m4_nut_t = 3.4;
m5_hole  = 5.4;
// Camera threads (nuts are captured in the end blocks)
q14_hole = 6.8;   q14_nut = 11.5; q14_nut_t = 6.0;   // 1/4"-20 nut, 7/16" AF
q38_hole = 9.9;   q38_nut = 14.7; q38_nut_t = 8.8;   // 3/8"-16 nut, 9/16" AF
b625_od  = 16.15; b625_w  = 5;                       // 625ZZ bearing

eps = 0.01;

// ---------- Helpers ----------
// hexagon given across-flats size
module hex(af, h) { cylinder(d = af / cos(30), h = h, $fn = 6); }

// horizontal hole along Y printable without supports (point at +Z)
// down = true puts the point at -Z (for parts printed upside down)
// clip  = how far (mm) the point may stick out beyond the circle
module teardrop_y(d, l, center = false, down = false, clip = 100) {
    translate([0, center ? l/2 : l, 0])
    rotate([90, 0, 0])
    mirror([0, down ? 1 : 0])
    linear_extrude(l)
    union() {
        circle(d = d);
        intersection() {
            rotate(45) square(d/2);
            translate([-d, 0]) square([2*d, d/2 + clip]);
        }
    }
}

// horizontal hole along X printable without supports (point at +Z)
module teardrop_x(d, l, center = false) {
    rotate([0, 0, -90]) teardrop_y(d, l, center);
}

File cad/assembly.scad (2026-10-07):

// Full assembly preview (not for printing)
include <parts.scad>
module roller() rotate([0, 90, 0]) difference() { cylinder(d = roller_od, h = roller_w, center = true); cylinder(d = 8, h = 8, center = true); }
car_pos = 0;   // carriage position along the rail (mm, 0 = centre)

ins = end_d - rod_insert;          // rod end inside the block
span = rail_len - 2 * ins;         // distance between the two block origins
y_m = -span/2;                     // motor end origin
y_i =  span/2;                     // idler end origin (mirrored)

color("SteelBlue") translate([0, y_m, 0]) motor_end();
color("SteelBlue") translate([0, y_i, 0]) mirror([0, 1, 0]) idler_end();
// rods
color("Silver") for (x = rod_xs)
    translate([x, -rail_len/2, rod_z]) rotate([-90, 0, 0]) cylinder(d = rod_d, h = rail_len);
// carriage + bearings
translate([0, car_pos, 0]) {
    color("Orange") carriage();
    // 608ZZ rollers: 2 on top + 1 underneath per track, M8 axles
    color("Silver") for (sx = [-1, 1]) {
        for (sy = [-1, 1]) translate([sx * track_sp/2, sy * roller_y, top_axle_z]) roller();
        translate([sx * track_sp/2, 0, bot_axle_z]) roller();
    }
    color("DimGray") for (sx = [-1, 1]) for (p = [[-roller_y, top_axle_z], [roller_y, top_axle_z], [0, bot_axle_z]])
        translate([sx * track_sp/2, p[0], p[1]]) rotate([0, 90, 0]) cylinder(d = 8, h = 2 * (cheek_out + cheek_t - track_sp/2) + 6, center = true);
    color("DarkOrange") for (sy = [-1, 1]) translate([0, sy * belt_clamp_y, belt_block_bottom - 1.6 - 4]) belt_clamp_plate();
    // ball head + camera (A7 IV + 24-70 GM II, approximate)
    color("DimGray") translate([0, 0, car_z0 + car_t]) cylinder(d = 40, h = 70);
    color("#222") translate([-65, -35, car_z0 + car_t + 70]) cube([131, 80, 96]);
    color("#111") translate([0, -35, car_z0 + car_t + 70 + 48]) rotate([90, 0, 0]) cylinder(d = 88, h = 120);
}
// motor
color("#333") translate([-14 - 5, y_m + pulley_y_motor, pulley_z]) rotate([0, -90, 0]) translate([-nema_w/2, -nema_w/2, 0]) cube([nema_w, nema_w, 40]);
// pulleys
for (yy = [y_m + pulley_y_motor, y_i - pulley_y_idler])
    color("Gold") translate([-8, yy, pulley_z]) rotate([0, 90, 0]) cylinder(d = 16, h = 16);
// belt (simplified)
color("#111") {
    pm = y_m + pulley_y_motor; pi = y_i - pulley_y_idler;
    translate([-3, pm, belt_top_z - 0.7]) cube([6, car_pos - belt_clamp_y - pm + 10, 1.4]);
    translate([-3, car_pos + belt_clamp_y - 10, belt_top_z - 0.7]) cube([6, pi - (car_pos + belt_clamp_y - 10), 1.4]);
    translate([-3, pm, pulley_z - pulley_pd/2 - 0.7]) cube([6, pi - pm, 1.4]);
}
// hand wheel
color("Tomato") translate([22, y_i - pulley_y_idler, pulley_z]) rotate([0, 90, 0]) hand_wheel();
// electronics box on the motor-end rear wall
color("SlateGray") translate([0, y_m - motor_bay_d, 40]) rotate([90, 0, 0]) elec_box();

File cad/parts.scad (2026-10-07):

// ============================================================
//  Camera Slider - all printable parts (modules)
//  Every module is modelled in its *assembled* position.
//  The *_print() wrappers re-orient a part for printing.
// ============================================================
include <config.scad>

// ------------------------------------------------------------
//  Rod-clamp section shared by both end blocks
//  occupies x = +-end_w/2, y = 0..end_d, z = 0..end_h
//  rods enter from the inner face (y = end_d)
// ------------------------------------------------------------
module end_rod_section() {
    difference() {
        // body with rounded top corners
        hull() {
            translate([-end_w/2, 0, 0]) cube([end_w, end_d, 1]);
            for (sx = [-1, 1])
                translate([sx * (end_w/2 - 8), 0, end_h - 8])
                    rotate([-90, 0, 0]) cylinder(r = 8, h = end_d);
        }

        for (x = rod_xs) {
            // rod socket (blind, rod stops at y = end_d - rod_insert)
            translate([x, end_d - rod_insert, rod_z]) teardrop_y(rod_hole, rod_insert + eps);
            // M4 set-screw from the top + captive nut slot from the inner face
            translate([x, end_d - rod_insert/2, rod_z]) cylinder(d = m4_hole, h = 50);
            translate([x - m4_nut/2, end_d - rod_insert/2 - m4_nut/2, rod_z + rod_d/2 + 2.5])
                cube([m4_nut, rod_insert, m4_nut_t]);
        }

        // KW11 micro-switch pocket (+X side, below the rods): the carriage's outer
        // cheek presses the lever. Switch body 20 x 10 x 6.4, M2 screws from the side.
        translate([cheek_out + cheek_t/2 - 3.3, end_d - 10.4, floor_t + 6]) {
            cube([6.6, 10.4 + eps, 20.5]);
            for (dz = [5.5, 15]) translate([-10, 3, dz]) rotate([0, 90, 0]) cylinder(d = 2.2, h = 30);
        }
        // switch wires up to the top channel
        translate([cheek_out + cheek_t/2, end_d - 5, floor_t + 20]) cylinder(d = 4, h = end_h);

        // belt passage (both runs)
        translate([-6, -eps, pulley_z - 11]) cube([12, end_d + 2*eps, 22 + 2]);

        // ---- tripod mounting: captured nuts, inserted from the inner face ----
        // 3/8"-16 in the centre
        translate([0, end_d/2, -eps]) cylinder(d = q38_hole, h = floor_t + 2);
        translate([0, end_d/2, floor_t]) hex(q38_nut, q38_nut_t);
        translate([-q38_nut/2, end_d/2, floor_t]) cube([q38_nut, end_d, q38_nut_t]);
        // two 1/4"-20
        for (sx = [-1, 1]) {
            translate([sx * 35, end_d/2, -eps]) cylinder(d = q14_hole, h = floor_t + 2);
            translate([sx * 35, end_d/2, floor_t]) rotate(30) hex(q14_nut, q14_nut_t);
            translate([sx * 35 - q14_nut/2, end_d/2, floor_t]) cube([q14_nut, end_d, q14_nut_t]);
        }

        // lightening / cable pockets between the tripod nuts and the rods
        for (sx = [-1, 1])
            translate([sx * 21 - 6, -eps, floor_t + 12]) cube([12, end_d + 2*eps, 14]);

        // endstop cable channel along the inner face (top)
        translate([-end_w/2 + 4, end_d - 4, end_h - 3]) cube([end_w - 8, 5, 3 + eps]);
    }
}

// ------------------------------------------------------------
//  MOTOR END   (rods at y = 0..end_d, motor bay at y < 0)
// ------------------------------------------------------------
module motor_end() {
    pt = 5;                         // motor plate thickness
    px = -14;                       // motor plate +X face (motor face sits here)
    union() {
        end_rod_section();
        difference() {
            union() {
                // floor
                translate([-end_w/2, -motor_bay_d, 0]) cube([end_w, motor_bay_d + eps, floor_t]);
                // motor plate
                translate([px - pt, -motor_bay_d, 0]) cube([pt, motor_bay_d + eps, pulley_z + nema_w/2 + 4]);
                // opposite bearing-free cheek (stiffness + belt guard)
                translate([14, -motor_bay_d, 0]) cube([pt, motor_bay_d + eps, pulley_z + 12]);
                // rear wall (electronics box mounts here)
                translate([-end_w/2, -motor_bay_d, 0]) cube([end_w, 5, 60]);
                // gussets
                for (gx = [-end_w/2, end_w/2 - 5])
                    translate([gx, -motor_bay_d, 0]) cube([5, motor_bay_d + eps, 30]);
            }
            // NEMA17 boss + screw holes (screws inserted from the pulley side)
            translate([px - pt - eps, pulley_y_motor, pulley_z]) {
                rotate([0, 90, 0]) cylinder(d = nema_boss, h = pt + 2);
                for (dy = [-1, 1], dz = [-1, 1])
                    translate([0, dy * nema_hole_sp/2, dz * nema_hole_sp/2])
                        rotate([0, 90, 0]) hull() {
                            // slotted 1 mm so belt tension can be trimmed
                            cylinder(d = m3_hole, h = pt + 2);
                            translate([0, 1, 0]) cylinder(d = m3_hole, h = pt + 2);
                        }
            }
            // electronics box screws (M4, 80 mm apart) + cable hole
            for (sx = [-1, 1])
                translate([sx * 40, -motor_bay_d - eps, 40]) rotate([-90, 0, 0]) cylinder(d = m4_hole, h = 10);
            translate([0, -motor_bay_d - eps, 50]) rotate([-90, 0, 0]) cylinder(d = 12, h = 10);
            // floor drain / weight holes
            for (sx = [-1, 1])
                translate([sx * 45, -motor_bay_d/2, -eps]) cylinder(d = 16, h = floor_t + 2);
        }
    }
}

// ------------------------------------------------------------
//  IDLER END  (hand-crank shaft on two 625ZZ bearings)
// ------------------------------------------------------------
module idler_end() {
    wt = 8;                     // wall thickness (holds a 5 mm wide 625ZZ)
    wx = 12;                    // inner face of each wall
    union() {
        end_rod_section();
        difference() {
            union() {
                translate([-end_w/2, -idler_bay_d, 0]) cube([end_w, idler_bay_d + eps, floor_t]);
                for (sx = [-1, 1])
                    translate([sx > 0 ? wx : -wx - wt, -idler_bay_d, 0])
                        hull() {
                            cube([wt, idler_bay_d + eps, pulley_z]);
                            translate([0, idler_bay_d + pulley_y_idler, pulley_z])
                                rotate([0, 90, 0]) cylinder(r = 14, h = wt);
                            translate([0, idler_bay_d - 1, 0]) cube([wt, 1, pulley_z + 14]);
                        }
                translate([-end_w/2, -idler_bay_d, 0]) cube([end_w, 5, 25]);
                for (gx = [-end_w/2, end_w/2 - 5])
                    translate([gx, -idler_bay_d, 0]) cube([5, idler_bay_d + eps, 25]);
            }
            // shaft + bearing seats (bearings pressed in from the outside)
            translate([0, pulley_y_idler, pulley_z]) {
                rotate([0, 90, 0]) cylinder(d = 6, h = 100, center = true);
                for (sx = [-1, 1])
                    translate([sx > 0 ? wx + wt - b625_w : -wx - wt - eps, 0, 0])
                        rotate([0, 90, 0]) cylinder(d = b625_od, h = b625_w + eps);
            }
            for (sx = [-1, 1])
                translate([sx * 45, -idler_bay_d/2, -eps]) cylinder(d = 16, h = floor_t + 2);
        }
    }
}

// ------------------------------------------------------------
//  CARRIAGE  (6x 608ZZ rollers on two twin-rod tracks, ball-head mount,
//  two belt clamps). Per track: 2 rollers on top, 1 preloaded underneath.
// ------------------------------------------------------------
belt_clamp_y = car_l/2 - 10;     // centre of each belt clamp block
belt_block_bottom = belt_top_z + 0.9;   // belt (1.4 mm) lies just below this face
top_axle_z = rod_z + roller_dz;
bot_axle_z = rod_z - roller_dz;

// one cheek plate, x0..x1, with a thicker boss around the bottom axle
module cheek(x0, x1, boss_dx) {
    difference() {
        union() {
            translate([x0, -car_l/2, top_axle_z - 9]) cube([x1 - x0, car_l, car_z0 - top_axle_z + 10]);
            hull() {
                translate([x0, -16, cheek_bot]) cube([x1 - x0, 32, 1]);
                translate([x0, -40, top_axle_z - 9]) cube([x1 - x0, 80, 1]);
            }
            translate([min(x0, x0 + boss_dx), -12, cheek_bot]) cube([x1 - x0 + abs(boss_dx), 24, 12]);
        }
        // windows between the rollers
        for (sy = [-1, 1])
            translate([x0 - 1, sy * 24 - 6, top_axle_z - 3]) cube([x1 - x0 + 2, 12, car_z0 - top_axle_z]);
    }
}
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

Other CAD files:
cad/print.scad

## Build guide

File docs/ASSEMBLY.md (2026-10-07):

# Assembly

assembly

Tools: 2.5 / 3 mm Allen keys, small pliers, soldering iron, multimeter, hacksaw (if rods need cutting).

## 1. Prepare the end blocks

1. **Tripod nuts.** Push the nuts into the slots on the **inner face** (the face where the rods go in):
   two **1/4"-20** nuts (outer) and one **3/8"-16** nut (centre) in each block. A drop of CA glue holds
   them. Screw a tripod screw in from below to pull each one fully into its hex pocket.
2. **Rod set-screw nuts.** Slide an **M4 nut** into each of the 4 slots on the inner face, above each rod
   socket, then start an **M4×16** screw from the top (don't tighten yet).

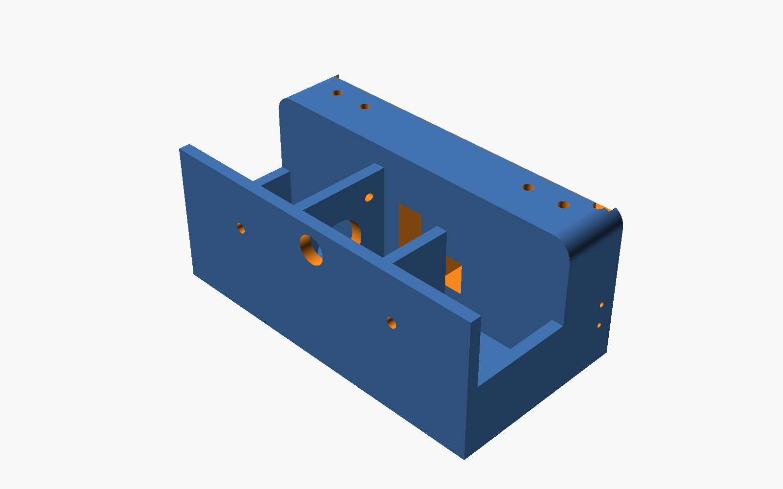
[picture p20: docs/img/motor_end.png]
motor end


## 2. Motor end

1. Put the **GT2 20T pulley** on the NEMA17 shaft, grub screw on the flat of the shaft. Don't tighten yet.
2. Lower the motor into the bay from above, on the side of the plate away from the belt slot.
   Its centring boss goes into the big plate hole and the shaft points toward the middle. Fix it with **4× M3×10** from the pulley side.
3. Slide the pulley so the teeth are in the middle of the belt slot. Tighten the grub screw.

## 3. Idler end (hand-crank)

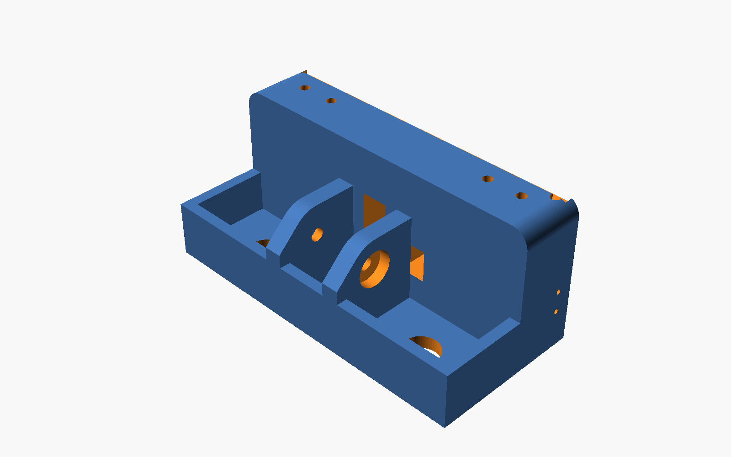
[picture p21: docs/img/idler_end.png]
idler end


1. Press a **625ZZ** bearing into the outside of each wall.
2. Slide the **5 mm shaft** in through one bearing, through the **GT2 pulley** (with M5 washers each
   side as spacers), then through the other bearing. Centre the pulley and tighten its grub screw.
3. Put the **hand wheel** on the long end of the shaft (side with ~20 mm sticking out). Tighten the
   M3 grub screw. Fit the **M5×30 bolt + spinner** into the wheel's outer hole as a crank handle.

*No crank wanted?* Use an M5×40 bolt + nyloc nut as the shaft and a toothless GT2 idler. The crank is
nice for slow manual moves with the belt still attached.

## 4. Carriage

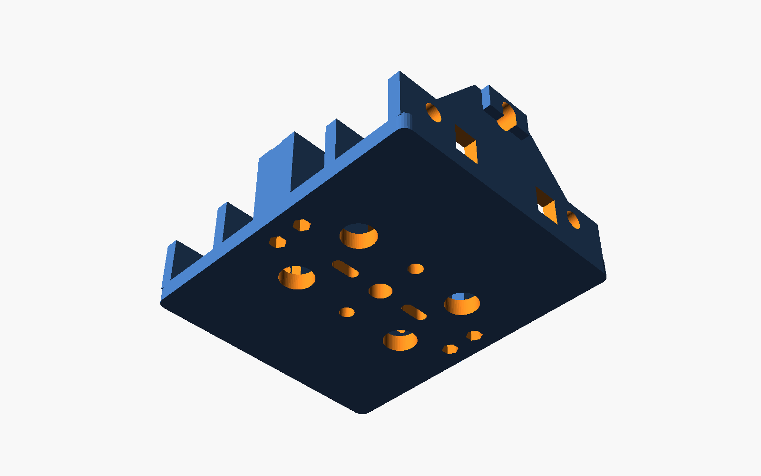
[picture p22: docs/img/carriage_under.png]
carriage underside


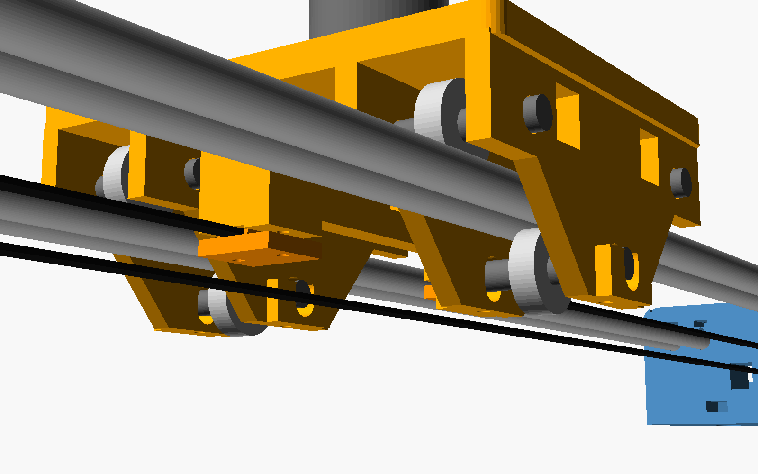
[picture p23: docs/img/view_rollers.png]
rollers


The carriage rides on **6 × 608ZZ** rollers. Each track (pair of rods) gets **2 rollers on top**, sitting in
the groove between the two rods, and **1 roller underneath** pushing up into the same groove. The rollers
touch each rod on a line at about 30°, so the carriage can't move sideways or lift. Every contact rolls;
nothing slides.

1. Drop **M3 nuts** into the 4 hex pockets on top of the belt-clamp blocks.
2. Top rollers (×4): **M8×50** bolt → washer → cheek → **spacer** → 608ZZ → **spacer** → cheek → washer
   → **nyloc**. Tighten until the bearing can't wobble but still spins freely. The spacer's small lip
   must touch only the bearing's **inner** ring.
3. Bottom rollers (×2) go in later (step 5) with **M8×60** bolts, the same way, through the slots.
4. Screw an **M4×12** a few turns into each of the 4 holes under the bottom slots (they push the
   bottom rollers up).

## 5. Rails

1. Push the **4 × 10 mm rods** into one end block until they bottom out, and tighten the 4 M4 set-screws
   (roll each rod on a flat table first. A bent rod wobbles; don't use it).
2. Set the carriage on the rods: the top rollers sit in the two grooves.
3. Push the other end block onto the rods and tighten its set-screws.
4. Fit the 2 **bottom rollers** (M8×60) from the sides, through the slots, under each rod pair.
5. **Preload:** for each bottom roller, loosen its nut, turn the two M4 push screws until the roller just
   touches both rods, then **¼ turn more**. Tighten the M8 nut. Do it with the camera on. Correct preload =
   no play when you try to lift or twist the carriage, but it still glides with one finger and doesn't
   "notch". Too tight shortens bearing life and makes it rough.
6. Slide it end to end. If one spot is tight, a rod is bent or the rods aren't parallel. Loosen the
   set-screws, let the carriage centre the rods, retighten.

> Keep the rods clean and wipe them with a drop of light oil (sewing-machine oil) on a cloth. Dust on the
> rods is the main cause of noise with rollers.

## 6. Belt

1. Clamp one belt end under the **motor-side** clamp block: belt **teeth down**, the **clamp plate** (teeth up)
   under it, **2× M3×16** from below.
2. Run the belt through the motor end, around the motor pulley, along the bottom, around the idler pulley
   and back to the carriage.
3. Pull it tight (it should "twang" like a low guitar string, not be rock hard). Clamp it with the second
   plate. Use the **thumb knob** on one of the two screws on this side: that's your quick release.
4. Fine tension: loosen the 4 motor screws, slide the motor in its 1 mm slots, retighten.

## 7. Endstops

Each end block has a pocket on its inner face, on the **+X side below the rods**. Push a **KW11** switch in
(lever facing the carriage) and fix it with **2× M2** screws from the outside of the block. The carriage's
outer roller cheek presses the lever before it reaches the block. Bend the lever slightly if it doesn't
click about 2 mm before the cheek touches the block. Wires go up through the small hole into the top
channel.

## 8. Electronics

Wire everything per [WIRING.md](WIRING.md), mount the perfboard in `elec_box`, and fix the box to the
motor end's rear wall with **2× M4×12 + nuts**. The cables go through the 12 mm hole.

**Before first power-up:** set the LM2596 output to **5.0 V** with the ESP32 *disconnected*. Set the
TMC2209 Vref (see wiring doc).

## 9. Flash the firmware

See [../firmware/README.md](../firmware/README.md).

## 10. First test

1. Power on with the camera **off** the slider.
2. Connect to Wi-Fi **CamSlider-XXXX** (password `slider123`) and open **http://192.168.4.1**.
3. Press **Home**. The carriage should move toward the **motor end**. If it goes the other way, press STOP,
   then open *Settings* and set *Invert dir* = 1 → Save.
4. Jog to the far end, check the reading, and set *Travel* to that value (minus a few mm).
5. Mount the ball head, then the camera.

## Mounting options

| Use | How |
|-----|-----|
| **2 tripods** | one tripod under each end block (1/4" or 3/8" thread). Level both. Best for long/heavy moves |
| **1 tripod** | under the **motor end** (heavier end) for short rails only, with the camera kept near that end. A second tripod or a light stand under the idler end is much better |
| **Table / floor** | sits on the flat bottoms of the end blocks. Add the **table feet** (screwed into a 1/4" nut) with rubber pads for a wider stance, or stick rubber pads on directly |
| **Angled** | different tripod heights. Keep the slope under ~30° and raise motor current a bit |

## Hand-driven modes

| Mode | How | Use |
|---|-----|-----|
| **Motor off** | app button / long-press the knob → `MOTOR OFF`. Driver releases the motor | push the carriage by hand, belt stays on. Push slowly: moving the motor fast makes it act as a generator |
| **Crank** | motor off + turn the hand wheel on the idler end | smooth, slow manual moves |
| **Fully free** | loosen the **thumb knob** and slip the belt out of the clamp | like a plain manual slider. Re-clamp and **HOME** after |
| **Electronic hand wheel** | turn the rotary knob on the box: 5 mm per click, press to switch to 0.5 mm | precise framing, motor holds position |

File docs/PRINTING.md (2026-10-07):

# Printing (Creality Ender-3 V3 / V3 SE / V3 KE)

All parts fit the 220 × 220 mm bed. Print them in the orientation the STL is already in.

## Material

**PETG** is recommended (stiffer, doesn't creep under the camera weight, survives a hot car).
PLA+ is OK for indoor use.

| Setting | PETG | PLA+ |
|---|---|---|
| Nozzle / bed | 235–245 °C / 70–80 °C | 210–220 °C / 60 °C |
| Layer height | 0.2 mm | 0.2 mm |
| Walls (perimeters) | **4** | 4 |
| Top / bottom layers | 5 / 5 | 5 / 5 |
| Fan | 30–50 % | 100 % |
| Supports | **none needed** | none |

## Parts

| STL | Qty | Infill | Notes |
|-----|-----|---|---|
| `motor_end.stl` | 1 | 40 % gyroid | flat on bed. Longest print (~6–7 h) |
| `idler_end.stl` | 1 | 40 % gyroid | flat on bed |
| `carriage.stl` | 1 | 40 % gyroid | already upside down (top plate on bed) |
| `belt_clamp_plate.stl` | 2 | 100 % | teeth up |
| `thumb_knob.stl` | 1 | 30 % | quick-release for hand mode |
| `hand_wheel.stl` | 1 | 30 % | crank on the idler shaft |
| `crank_spinner.stl` | 1 | 30 % | spins on an M5×30 bolt |
| `roller_spacer.stl` | **12** | 100 % | 2 per roller, lip toward the bearing |
| `table_foot.stl` | 2 | 30 % | optional – wider stance on a table |
| `elec_box.stl` | 1 | 20 % | |
| `elec_lid.stl` | 1 | 20 % | outside face on the bed |
| `encoder_knob.stl` | 1 | 30 % | optional |

Total ≈ 550–650 g of filament.

## Fit tuning

Before the big parts, print a small test: a 15 mm cube with a 10.25 mm hole (or just print one end block
first) and check your rods fit.

* Rod too loose/tight → change `rod_hole` in `cad/config.scad`.
* M8 bolts tight in the cheeks → drill the holes with an 8.5 mm drill (don't widen them in CAD, they should be snug).
* Your rods aren't 10 mm, or you want a different gap between the 2 rods of a track → change `rod_d` and `pair_sp`.
  Roller height (`roller_dz`) and the carriage height follow automatically.
* Nuts don't fit → adjust `m3_nut`, `m4_nut`, `q14_nut`, `q38_nut`.

Then run `./cad/export_stl.sh` (needs [OpenSCAD](https://openscad.org)) to regenerate all STLs.

## Different rail length / rods

* Rail length: just cut the rods. Set the firmware travel to match: `SET travel <mm>`, `SAVE`.
  Usable travel ≈ rod length − 52 mm (inside the blocks) − 120 mm (carriage) − ~20 mm (endstop levers).
  800 mm rods → ~600 mm travel. 1000 mm rods → ~800 mm.
* With 4 × 10 mm rods the load is shared by all four. With the A7 IV + 24-70 GM II in the middle and a
  tripod at each end, they bend about **0.5 mm at 800 mm** and about **1 mm at 1000 mm**. That's fine for video.
  For longer rails, add a third tripod/light stand in the middle under a rod clamp, or use thicker rods.

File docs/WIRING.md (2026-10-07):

# Wiring

```
 12 V adapter / 3S battery
        │
   DC jack ── rocker switch ──┬───────────────► TMC2209  VM   (+100 µF 35 V across VM/GND)
                              │
                              └─► LM2596 IN+   (set OUT to 5.0 V BEFORE connecting the ESP32!)
                                   LM2596 OUT+ ─► ESP32 VIN (5V pin)
 all GND tied together ◄──────────── LM2596 GND, TMC2209 GND (both), ESP32 GND
```

## ESP32 DevKit V1 pin map

| ESP32 pin | Goes to | Notes |
|---|---|---|
| VIN (5V)  | LM2596 OUT+ (5.0 V) | |
| GND | common ground | |
| 3V3 | TMC2209 **VIO / VDD**, **MS1**, **MS2** | MS1 = MS2 = high → 1/16 microstep |
| GPIO 25 | TMC2209 **STEP** | |
| GPIO 26 | TMC2209 **DIR**  | wrong direction? send `SET invert 1` then `SAVE` |
| GPIO 27 | TMC2209 **EN** | low = motor on; high = hand mode |
| GPIO 32 | MIN endstop (motor end) **NO** contact | switch **COM → GND** |
| GPIO 33 | MAX endstop (idler end) **NO** contact | switch **COM → GND** |
| GPIO 18 | KY-040 **CLK** *(optional)* | encoder **+ → 3V3**, **GND → GND** |
| GPIO 19 | KY-040 **DT**  *(optional)* | |
| GPIO 5 | KY-040 **SW**  *(optional)* | |
| GPIO 16 | Button 1 "RUN" → GND *(optional)* | |
| GPIO 17 | Button 2 "STOP" → GND *(optional)* | |
| GPIO 4 | 330 Ω → LED → GND *(optional)* | onboard LED (GPIO 2) shows the same |
| GPIO 23 | 1 kΩ → PC817 pin 1 *(optional)* | PC817 pin 2 → GND |

TMC2209 also: **PDN/UART** – leave unconnected; **CLK** – unconnected (or GND); **DIAG / INDEX** – unconnected.

## Motor

NEMA17 4 wires: the two wires of **one coil** go to **1A / 1B** (some boards print **A1 / A2** or **2B 2A 1A 1B**),
the other coil to **2A / 2B**. To find a coil: wires that show a few ohms between them on a multimeter
(or make the shaft hard to turn when shorted together) are one coil.
If the motor only buzzes, swap the two wires of **one** coil.

⚠️ Never plug/unplug the motor while the driver has power – it kills TMC2209s.

### Motor current (Vref)

Turn the small pot on the TMC2209 with power on, measure between the pot and GND.

* Start at **Vref ≈ 1.0 V** (≈ 0.7–0.9 A RMS on most modules) – enough for this slider when level.
* Vertical / steep angle use: raise toward **1.3 V**.
* Motor too hot to touch for more than a few seconds → lower it.

Check your module's page – the exact formula differs between BigTreeTech, FYSETC and clones.

## Endstops

Micro switch (KW11): **COM → GND**, **NO → GPIO 32 (motor end)** / **GPIO 33 (idler end)**. Leave NC empty.
No switches? Send `SET endstops 0`, `SAVE` – then use **ZERO** to set 0 wherever the carriage is.

## Camera shutter (time-lapse, optional)

```
GPIO23 ── 1 kΩ ──► PC817 pin 1 (anode)          PC817 pin 4 (collector) ──► camera "shutter" wire
GND    ──────────► PC817 pin 2 (cathode)        PC817 pin 3 (emitter)   ──► camera "ground" wire
```

The **Sony A7 IV** has no 2.5 mm remote jack; its wired remote uses the **Multi/Micro USB** terminal.
The easiest route is a cheap "Sony Multi terminal shutter release cable" (RM-VPR1 clone): cut it, find the
shutter and ground wires (they short when the button is pressed fully) and connect them to the PC817.
**Without a cable** you can still do time-lapse: use the camera's built-in **Interval Shooting** and run
the slider with a long `RUN` (e.g. `RUN 1800` = 30 min continuous slide).

## Power notes

* 12 V **2 A** adapter is plenty (the motor draws < 1 A at this setting).
* Battery: 3× 18650 in series with a **3S BMS** (≈ 11.1 V nominal, 12.6 V full). Runs for hours.
* Don't power from USB and 12 V at the same time unless your ESP32 board has a diode on VIN
  (most DevKit V1 do – check for a small diode next to the USB connector). Switch 12 V off when flashing.

## Perfboard layout suggestion (7 × 5 cm)

```
 ┌───────────────────────────────────────────────┐
 │  [ ESP32 DevKit on female headers ]            │
 │                                                │
 │  [TMC2209 on headers]   (100µF)   [LM2596]     │
 │  motor 4-pin  endstop 2×2-pin  12V screw term. │
 └───────────────────────────────────────────────┘
```
Use female headers so the ESP32 and driver can be removed/replaced. The box (`elec_box.stl`) has
standoffs for a 70 × 50 mm board (64 × 44 mm hole pattern, M2.5 screws / self-tapping M3).

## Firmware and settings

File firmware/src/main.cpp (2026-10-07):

// ============================================================
//  DIY Camera Slider - ESP32 firmware
//  Control: Wi-Fi web page, Bluetooth LE, USB serial, rotary knob + 2 buttons
// ============================================================
#include <Arduino.h>
#include "config.h"
#include "settings.h"
#include "motion.h"
#include "commands.h"
#include "net.h"

// ---------------- rotary encoder (electronic hand wheel) ----------------
static volatile int32_t encCount = 0;
static volatile uint8_t encState = 0;

static void IRAM_ATTR encIsr() {
    // full quadrature decode; KY-040 gives 4 counts per detent
    static const int8_t table[16] = {0, -1, 1, 0, 1, 0, 0, -1, -1, 0, 0, 1, 0, 1, -1, 0};
    encState = ((encState << 2) | (digitalRead(PIN_ENC_A) << 1) | digitalRead(PIN_ENC_B)) & 0x0F;
    encCount += table[encState];
}

// ---------------- buttons with short / long press ----------------
struct Button {
    uint8_t  pin;
    bool     down = false, longFired = false;
    uint32_t t0 = 0;
    explicit Button(uint8_t p) : pin(p) {}
    // returns 1 = short press (on release), 2 = long press (after 800 ms)
    int poll() {
        bool pressed = digitalRead(pin) == LOW;
        uint32_t now = millis();
        if (pressed && !down) { down = true; longFired = false; t0 = now; }
        else if (pressed && down && !longFired && now - t0 > 800) { longFired = true; return 2; }
        else if (!pressed && down) {
            down = false;
            if (!longFired && now - t0 > 30) return 1;
        }
        return 0;
    }
};
static Button btnRun(PIN_BTN_RUN), btnStop(PIN_BTN_STOP), btnEnc(PIN_ENC_SW);
static bool fineJog = false;

static void reply(const char *src, const String &r) {
    if (r.length()) Serial.printf("[%s] %s\n", src, r.c_str());
}

static void localControls() {
    // knob: jog 5 mm per click (0.5 mm in fine mode)
    static int32_t lastDetent = 0;
    int32_t det = encCount / 4;
    if (det != lastDetent) {
        int32_t d = det - lastDetent;
        lastDetent = det;
        if (motionIsBusy() && motionMode() != Mode::Move) motionStop();
        else reply("knob", runCommand("JOG " + String(d * (fineJog ? 0.5f : 5.0f), 2)));
    }

    switch (btnRun.poll()) {
        case 1: reply("btn", motionIsBusy() ? (motionStop(), String("ok stop")) : runCommand("RUN")); break;
        case 2: reply("btn", runCommand("SETA")); break;
    }
    switch (btnStop.poll()) {
        case 1: motionStop(); reply("btn", "ok stop"); break;
        case 2: reply("btn", runCommand("SETB")); break;
    }
    switch (btnEnc.poll()) {
        case 1: fineJog = !fineJog; reply("knob", fineJog ? "fine jog 0.5 mm" : "coarse jog 5 mm"); break;
        case 2: reply("knob", runCommand(motionMotorOn() ? "MOTOR OFF" : "MOTOR ON")); break;
    }
}

// LED: solid = ready, slow blink = not homed, fast blink = moving, double blink = hand mode
static void statusLed() {
    uint32_t t = millis();
    bool on;
    if (!motionMotorOn())       on = (t % 1500) < 100 || ((t % 1500) > 250 && (t % 1500) < 350);
    else if (motionIsBusy())    on = (t / 100) % 2;
    else if (!motionIsHomed())  on = (t / 600) % 2;
    else                        on = true;
    digitalWrite(PIN_LED, on);
    digitalWrite(PIN_LED_ONBOARD, on);
}

// ------------------------------------------------------------
void setup() {
    Serial.begin(115200);
    delay(200);
    Serial.println("\n=== DIY Camera Slider ===");

    pinMode(PIN_LED, OUTPUT);
    pinMode(PIN_LED_ONBOARD, OUTPUT);
    pinMode(PIN_ENC_A, INPUT_PULLUP);
    pinMode(PIN_ENC_B, INPUT_PULLUP);
    pinMode(PIN_ENC_SW, INPUT_PULLUP);
    pinMode(PIN_BTN_RUN, INPUT_PULLUP);
    pinMode(PIN_BTN_STOP, INPUT_PULLUP);
    attachInterrupt(digitalPinToInterrupt(PIN_ENC_A), encIsr, CHANGE);
    attachInterrupt(digitalPinToInterrupt(PIN_ENC_B), encIsr, CHANGE);

    settingsLoad();
    motionInit();
    netInit();
    bleInit();
    if (cfg.homeOnBoot) reply("boot", motionHome());
    Serial.println("Type HELP for commands.");
}

void loop() {
    static String line;
    while (Serial.available()) {
        char ch = Serial.read();
        if (ch == '\n' || ch == '\r') {
            if (line.length()) { reply("usb", runCommand(line)); line = ""; }
        } else if (line.length() < 200) line += ch;
    }
    motionLoop();
    netLoop();
    bleLoop();
    localControls();
    statusLed();
}

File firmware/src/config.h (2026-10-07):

#pragma once
// ============================================================
//  Pin map and defaults - see docs/WIRING.md
// ============================================================

// --- TMC2209 (STEP/DIR standalone mode, MS1 = MS2 = 3V3 -> 1/16 step) ---
#define PIN_STEP        25
#define PIN_DIR         26
#define PIN_EN          27      // LOW = driver enabled

// --- End stops (micro switch to GND, NO contact) ---
#define PIN_END_MIN     32      // motor end  (position 0)
#define PIN_END_MAX     33      // idler end  (position = travel)

// --- Optional local controls ---
#define PIN_ENC_A       18      // KY-040 CLK
#define PIN_ENC_B       19      // KY-040 DT
#define PIN_ENC_SW      5       // KY-040 SW
#define PIN_BTN_RUN     16      // button 1: run / long = set A
#define PIN_BTN_STOP    17      // button 2: stop / long = set B
#define PIN_LED         4       // status LED (+330R), onboard LED is GPIO2
#define PIN_LED_ONBOARD 2
#define PIN_SHUTTER     23      // PC817 opto -> camera remote (time-lapse)

// --- Mechanics defaults (changeable with SET ... / SAVE) ---
// 200 steps/rev * 16 microsteps / (20 teeth * 2 mm) = 80 steps/mm
#define DEF_STEPS_PER_MM   80.0f
#define DEF_MAX_SPEED      120.0f   // mm/s
#define DEF_ACCEL          250.0f   // mm/s^2
#define DEF_TRAVEL         600.0f   // usable travel for an 800 mm rail (see docs)
#define DEF_HOME_SPEED     25.0f    // mm/s
#define HOME_BACKOFF_MM    3.0f

#define AP_SSID_PREFIX     "CamSlider-"
#define DEF_AP_PASS        "slider123"   // >= 8 chars
#define MDNS_NAME          "slider"      // http://slider.local
#define BLE_NAME           "CamSlider"

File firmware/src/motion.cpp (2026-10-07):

#include "motion.h"
#include "config.h"
#include "settings.h"
#include <FastAccelStepper.h>

static FastAccelStepperEngine engine;
static FastAccelStepper *st = nullptr;

static Mode     mode    = Mode::Idle;
static bool     homed   = false;
static bool     motorOn = true;
static int32_t  target  = 0;           // steps
static String   lastMsg = "";

// homing
static uint8_t  homePhase = 0;
// A-B / sequence
static int      legsLeft = 0;          // <0 = forever
static bool     legToB   = true;
static bool     prepos   = false;      // currently driving to the start point
static float    jobSecs = 0, jobEase = 0;
static int      seqIdx = 0, seqDir = 1, seqLoops = 0;
// time-lapse
static int      tlShots = 0, tlShot = 0, tlSettle = 0, tlShutter = 0;
static uint32_t tlInterval = 0, tlNextAt = 0, tlPhaseAt = 0;
static uint8_t  tlPhase = 0;           // 0 move, 1 settle, 2 shoot, 3 wait
// shutter
static uint32_t shutterOffAt = 0;

// ------------------------------------------------------------
static inline int32_t mmToSteps(float mm) { return lroundf(mm * cfg.stepsPerMm); }
static inline float   stepsToMm(int32_t s) { return s / cfg.stepsPerMm; }
static inline bool    endMin() { return cfg.useEndstops && digitalRead(PIN_END_MIN) == LOW; }
static inline bool    endMax() { return cfg.useEndstops && digitalRead(PIN_END_MAX) == LOW; }

static float clampTravel(float mm) {
    if (mm < 0) return 0;
    if (mm > cfg.travel) return cfg.travel;
    return mm;
}

static void setSpeedMm(float v, float a) {
    float hz = v * cfg.stepsPerMm;
    if (hz < 0.07f) hz = 0.07f;          // library limit: ~250 M ticks (15.6 s) per step
    st->setSpeedInMilliHz((uint32_t)(hz * 1000.0f));
    int32_t acc = (int32_t)(a * cfg.stepsPerMm);
    st->setAcceleration(acc < 1 ? 1 : acc);
}

static void startMove(float mm, float v, float a) {
    target = mmToSteps(clampTravel(mm));
    setSpeedMm(v, a);
    st->moveTo(target);
}

// timed move: speed + accel chosen so the move takes `secs` with `easePct` ramps
static float startTimed(float mm, float secs, float easePct) {
    mm = clampTravel(mm);
    float d = fabsf(mm - motionPos());
    if (d < 0.01f) { target = mmToSteps(mm); return 0; }
    if (secs < 0.2f) secs = 0.2f;
    float tr = (easePct / 100.0f) * secs / 2.0f;     // ramp-up time (= ramp-down)
    if (tr < 0.05f) tr = 0.05f;
    if (tr > secs / 2.0f) tr = secs / 2.0f;
    float v = d / (secs - tr);
    float a = v / tr;
    if (v > cfg.maxSpeed) { v = cfg.maxSpeed; a = max(a, cfg.accel); }
    startMove(mm, v, a);
    return v;
}

static bool needHomed(String &err) {
    if (!motorOn) { err = "err motor is off (hand mode) - send MOTOR ON"; return false; }
    if (!homed)   { err = "err not homed - send HOME (or ZERO without endstops)"; return false; }
    return true;
}

static void finishJob(const char *msg) {
    mode = Mode::Idle;
    lastMsg = msg;
}

// ------------------------------------------------------------
void motionInit() {
    pinMode(PIN_END_MIN, INPUT_PULLUP);
    pinMode(PIN_END_MAX, INPUT_PULLUP);
    pinMode(PIN_SHUTTER, OUTPUT);
    digitalWrite(PIN_SHUTTER, LOW);

    engine.init();
    st = engine.stepperConnectToPin(PIN_STEP);
    if (!st) { Serial.println("stepper init failed"); return; }
    st->setDirectionPin(PIN_DIR, !cfg.invertDir);
    st->setEnablePin(PIN_EN, true);       // low active
    st->setAutoEnable(false);
    st->enableOutputs();
    motionApplySettings();
    if (!cfg.useEndstops) homed = true;   // position 0 = where it was switched on
}

void motionApplySettings() {
    if (!st) return;
    st->setDirectionPin(PIN_DIR, !cfg.invertDir);
    setSpeedMm(cfg.maxSpeed, cfg.accel);
}

void shutterPulse(int ms) {
    digitalWrite(PIN_SHUTTER, HIGH);
    shutterOffAt = millis() + (uint32_t)max(ms, 20);
}

// ------------------------------------------------------------
String motionHome() {
    if (!motorOn) return "err motor is off (hand mode)";
    motionStop();
    if (!cfg.useEndstops) { st->setCurrentPosition(0); target = 0; homed = true; return "ok zeroed (endstops disabled)"; }
    homed = false;
    mode = Mode::Homing;
    homePhase = 0;
    lastMsg = "homing";
    return "ok homing";
}

String motionZero() {
    motionStop();
    st->setCurrentPosition(0);
    target = 0;
    homed = true;
    return "ok position set to 0";
}

String motionGoto(float mm, float speed) {
    String e; if (!needHomed(e)) return e;
    if (speed <= 0 || speed > cfg.maxSpeed) speed = cfg.maxSpeed;
    mode = Mode::Move;
    startMove(mm, speed, cfg.accel);
    return "ok goto " + String(clampTravel(mm), 1);
}

String motionJog(float d) {
    if (!motorOn) return "err motor is off (hand mode)";
    if (mode != Mode::Idle && mode != Mode::Move) return "err busy";
    if (!st->isRunning()) target = st->getCurrentPosition();   // drop any stale target
    mode = Mode::Move;
    int32_t t = target + mmToSteps(d);
    if (homed) {
        int32_t lo = 0, hi = mmToSteps(cfg.travel);
        t = constrain(t, lo, hi);
    }
    target = t;
    setSpeedMm(min(cfg.maxSpeed, 60.0f), cfg.accel);
    st->moveTo(target);
    return "ok jog";
}

String motionTimedMove(float mm, float secs, float easePct) {
    String e; if (!needHomed(e)) return e;
    mode = Mode::Move;
    float v = startTimed(mm, secs, easePct);
    return "ok move v=" + String(v, 2) + "mm/s";
}

String motionRunAB(float secs, float easePct, int legs) {
    String e; if (!needHomed(e)) return e;
    if (fabsf(cfg.posA - cfg.posB) < 1) return "err A and B are the same";
    jobSecs = secs; jobEase = easePct;
    legsLeft = legs <= 0 ? -1 : legs;
    // start from whichever end we are closer to
    float p = motionPos();
    legToB = fabsf(p - cfg.posA) <= fabsf(p - cfg.posB);
    prepos = true;
    mode = Mode::RunAB;
    startMove(legToB ? cfg.posA : cfg.posB, cfg.maxSpeed, cfg.accel);
    return String("ok run ") + (legToB ? "A->B" : "B->A");
}

String motionSequence(int loops) {
    String e; if (!needHomed(e)) return e;
    if (cfg.nKeys < 2) return "err need at least 2 keyframes (KEY ADD)";
    seqIdx = 0; seqDir = 1;
    seqLoops = loops <= 0 ? -1 : loops;
    prepos = true;
    mode = Mode::Sequence;
    startMove(cfg.keys[0].pos, cfg.maxSpeed, cfg.accel);
    return "ok sequence";
}

static float tlPosFor(int i) {
    float f = tlShots > 1 ? (float)i / (tlShots - 1) : 1.0f;
    float s = f * f * (3 - 2 * f);                       // smoothstep
    float e = constrain(cfg.easePct, 0.0f, 100.0f) / 100.0f;
    f = f * (1 - e) + s * e;
    return cfg.posA + (cfg.posB - cfg.posA) * f;
}
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

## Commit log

2026-10-07 Add shopping/search list for slider parts
    Claude-Session: https://claude.ai/code/session_01SqF5Pe69mxhmUXgiDT72ZB
    [SHOPPING_LIST.csv, config.scad, parts.scad]
2026-10-07 Add camera slider: printable parts, ESP32 firmware, docs
    - Parametric OpenSCAD design for 12 mm rods + LM12UU, sized for Sony A7 IV + 24-70 GM II;
    STLs for Ender-3 V3 (end blocks with 1/4" + 3/8" tripod nuts, carriage, hand crank,
    quick-release belt clamp, endstop clips, table feet, electronics box)
    - ESP32 firmware: TMC2209 via FastAccelStepper, Wi-Fi web UI, BLE UART, rotary knob and
    buttons; A-B eased moves, bounce, keyframes, time-lapse, stop motion, hand mode
    - Wiring, printing, assembly and command docs
    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
    [assembly.scad, belt_clamp_plate.stl, carriage.stl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]
2026-10-07 Add assembly preview renders
    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
2026-10-07 Add soldering flux and supplies to shopping list
    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
    [SHOPPING_LIST.csv]
2026-10-07 Replace LM12UU bushings with 608ZZ rollers on 4x10 mm twin-rod tracks
    Each track is two 10 mm rods; two 608ZZ rollers ride on top in the groove
    between them and one preloaded roller presses up from below, giving a
    zero-play rolling carriage. End blocks now hold four rods and carry a
    built-in endstop pocket; endstop clip replaced by roller spacers.
    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
    [SHOPPING_LIST.csv, assembly.scad, belt_clamp_plate.stl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]
2026-11-01 Modular CAD: identical end blocks with bolt-on motor/crank pods, spring-preloaded rollers
    - end_block (print 2) with a 4x M4 pod interface; motor_pod and crank_pod bolt on
    - bottom rollers float on two bed-levelling springs each (constant preload, no binding)
    - carriage gets a 40x40 M4 module interface on top
    - electronics box resized for ESP32 + TMC2209 + LM2596, 3x GX12 sockets, 11 mm DC jack
    - check_fit.sh: interference tests + Ender-3 V3 bed-size check (all clear)
    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
2026-11-01 Docs for the modular build: Egyptian shop links, dimensions, wiring diagram, perfboard layout
    - SHOPPING_LIST.md/.csv rebuilt from product pages found on the listed Egyptian shops
    - DIMENSIONS.md: module interfaces, key heights, travel/belt table, part sizes, bought-part dims
    - wiring.svg + perfboard.svg (to scale), GX12 pinout, box layout
    - ASSEMBLY.md rewritten for pods, spring preload and a low-friction checklist
    - PRINTING.md: new part list, print order and fit tests
    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
